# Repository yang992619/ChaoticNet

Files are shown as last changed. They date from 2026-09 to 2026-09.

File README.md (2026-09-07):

# ChaoticNet

双摆混沌系统的物理约束神经网络预测 · 物理竞赛项目（截稿 2026-09-15）

研究问题：在本科实验室级精度（初值估计 ±0.5°、60fps 手机相机、手动释放且初值由视频反演）下，对比纯数据驱动 (Reservoir Computing) 和物理约束 NN (PINN) 对混沌轨迹的可信预测窗口。论点：高保真物理建模 + 物理结构能把可信视界扩到 ESN 的数倍（Hybrid 仿真内约 7×、真实零样本约 2.7×）。

> 权威数字以 `data/canonical_results_B.md` 为准（分布质量 B 口径，`tools/demo_doctor.py` 自动核验）。文档/PPT/论文凡与之冲突的旧值均以此源为唯一真相。

---

## 一、目录结构

```
ChaoticNet/
├── README.md                       本文件，项目总入口
├── CHANGELOG.md                    变更日志（最新 v3.1）
│
├── 文档/                           所有中文文档（2026-06-23 起统一归档于此）
│   ├── 报告与计划/                  项目执行计划（14 周 + 5 人分工）、成员贡献说明、
│   │                               人工智能使用声明、实验仪器说明、审校报告、冲刺计划书
│   ├── 操作手册/                    拍摄操作说明书、相机标定教程、视觉追踪交接、实验清单
│   └── 答辩/                       答辩讲稿、逐页讲稿、PPT 大纲、学习清单
│
├── diagrams/                       图纸（理论 + 装置 + 加工）
│   ├── README.md                   3 张主图速览 + 关键设计理由
│   ├── 01_physics_model.svg        双摆理论模型（θ₁/θ₂/L₁/L₂/m₁/m₂）
│   ├── 02_mechanical_front_view.svg 装置正视装配图（含尺寸）
│   ├── 03_camera_setup_top_view.svg 视觉测量俯视布置
│   ├── 04_frame_assembly.svg       框架装配步骤
│   └── parts/                      四件加工图（发加工厂）
│       ├── BOM.md                  物料清单（576-753 元）
│       ├── 组装书.md                两天装配手册（含力矩 + 验收）
│       ├── 轴承.md                  MR105ZZ 轴承规格 + 脱脂步骤
│       ├── 轴销.md                  P05/P06 圆柱销规格（v2 已缩短至 12/15mm）
│       ├── generate_dxf.py         三件铝板 DXF 生成脚本
│       ├── P01_arm_1.{svg,pdf}     摆臂 1（6061-T6 4mm，R12.5）
│       ├── P02_arm_2.{svg,pdf}     摆臂 2（6061-T6 4mm，R12.5）
│       ├── P03_brass_weight.{svg,pdf}  配重盘 v2.1（45# 钢 ⌀30×12mm，66g）
│       ├── P04_pivot_bracket.{svg,pdf} 主轴座（6061-T6 5mm，R10）
│       └── dxf/                    四份 DXF 直接发激光厂
│
├── sim/                            数值仿真（GT 对照）
│   ├── baseline.py                 无阻尼 RK45 解拉格朗日方程，50 组随机初值
│   ├── baseline_distmass.py        分布质量 B 版（头条数据底座），50 组
│   ├── baseline_damped.py          阻尼版，实测拟合 b ≈ 1.66e-5 N·m·s/rad
│   ├── fit_damping.py              能量耗散率法从实测反推粘性 + 二次空气阻力
│   ├── lyapunov.py                 50 组自测最大 Lyapunov 指数 → τ_L
│   ├── visualize.py                4 张图（时间序列/xy 轨迹/相空间/能量）
│   ├── animate.py                  单次仿真摆动 mp4
│   ├── animate_compare.py          三色对比 mp4（GT 白 / ESN 蓝 / PINN 红）
│   ├── plot_horizon_50.py          50 组视界分布四联图
│   └── plot_three_way.py           ESN / PINN / Hybrid 三方对比图
│
├── rc/                             AI 预测模型
│   ├── esn.py                      Echo State Network 基线 (~290 行)
│   ├── pinn.py                     物理约束 NN 基线 (~350 行，含 model.pt 保存)
│   ├── hybrid.py                   解析-NN 混合模型 (~180 行)
│   ├── lnn.py                      Lagrangian NN（Cranmer 2020，训练不稳，归档 future work）
│   ├── sweep_50.py                 50 组 ESN+PINN 评估（无阻尼）
│   ├── sweep_damped.py             50 组 PINN vs Hybrid 评估（阻尼）
│   ├── real_validation_multi.py    29 段真实录像零样本评估
│   ├── error_decomposition.py      真实短视界的三天花板误差分解
│   └── sensitivity.py              ±0.1°/0.5°/1.0° 初值精度敏感性扫描
│
├── tools/                          自动化工具 + loop 监控
│   ├── smoke.py                    项目自检（< 30 秒）
│   ├── acceptance.py               W3 装置验收（τ / 重复性 / 棋盘格）
│   ├── paper_audit.py              paper/README/csv 一致性 loop（A–F 六项检查）
│   ├── demo_doctor.py              头条数字与 canonical_results_B.md 自动核验
│   ├── live_demo.py                答辩交互演示：评委输初值，看三摆赛跑
│   ├── overlay_real_prediction.py  实拍视频上叠加零样本预测轨迹
│   ├── build_canonical_distmass.py 训练并冻结 canonical 权重（分布质量）
│   ├── canon_multirun_distmass.py  多 run 头条统计（仿真内 + 真实）
│   ├── lambda_ablation_distmass.py 物理损失权重消融（分布质量重跑）
│   ├── hp_sweep.py                 PINN 超参/架构 sweep（写 leaderboard）
│   ├── fair_compare.py             公平四方对比（ESN/PINN/Hybrid/λ=0 同 N 同 epoch）
│   ├── multi_seed.py               多 seed 鲁棒性（3 λ × 5 seed）
│   └── data_size_ablation.py       训练数据量 ablation（2/5/10/20/50 trial）
│
├── tracking/                       视觉追踪
│   ├── track_pendulum.py           ★ 正式管线：29 段 canonical CSV 由它产出（HSV / Lab 双检测路径）
│   ├── reproduce_29.sh             由源视频重建 29 段逐帧 CSV（逐段 --t0/--t1，抽验 5 段 md5 一致）
│   └── track.py                    早期版本，仅合成视频验证（0.12° 中位误差），非论文数据来源
│
├── paper/                          论文（36 页 PDF，含 3 节消融附录）
│   ├── main.tex                    中文 LaTeX (ctex) 主文件，9 章 + 摘要 + 目录 + 文献 + 4 附录
│   ├── references.bib              24 篇文献（双摆/ESN/PINN/SciML/视觉/阻尼/气象大模型）
│   ├── texstyles/gb7714/           GB/T 7714—2015 参考文献样式（随项目自带）
│   ├── main.pdf                    编译产物（最新版本，36 页）
│   └── 编译说明.md                  xelatex + biber 编译流程（含 TEXINPUTS 设置）
│
└── data/                           所有数据 + 图
    ├── canonical_results_B.md              ★ 全项目数字唯一真相源（分布质量 B 口径）
    ├── sim_distmass/                       分布质量 B 仿真数据（头条数据底座）
    ├── canon_multirun/                     canonical 多 run 统计（论文头条表来源）
    ├── real_validation/                    29 段真实录像零样本结果 + 图
    ├── ablation_distmass/                  分布质量口径下的消融重跑
    ├── sim/                                无阻尼 baseline 数据
    │   ├── trial_000.csv ~ trial_049.csv   50 组仿真轨迹（30s @ 120fps）
    │   ├── summary.csv                     初值 + 能量漂移汇总
    │   └── figures/                        + v1_baseline 存档 + 三色对比 mp4
    ├── sim_damped/                         阻尼仿真数据（v3 ground truth）
    │   └── trial_000.csv ~ trial_049.csv   50 组阻尼轨迹
    ├── rc/                                 ESN 输出
    │   ├── esn_summary.csv / esn_summary_50.csv
    │   └── figures/
    ├── pinn/                               PINN 输出 + 权重缓存
    │   ├── pinn_summary.csv / pinn_summary_50.csv
    │   ├── train_history.csv / model.pt
    │   └── figures/
    ├── hybrid/                             Hybrid 输出
    │   ├── hybrid_summary_50.csv / model.pt
    │   └── train_history.csv
    ├── hybrid_damped/                      PINN vs Hybrid on 阻尼数据
    │   ├── pinn_summary_damped.csv / hybrid_summary_damped.csv
    │   ├── pinn_damped_model.pt / hybrid_damped_model.pt
    │   └── compare_damped.csv
    ├── sensitivity/                        初值精度敏感性
    │   ├── sensitivity.csv / sensitivity_summary.csv
    │   └── sensitivity_box.png
    ├── tracking/                           视觉追踪逐帧结果（459M，未入库，见 .gitignore）
    │   ├── tracked_<tag>.csv               29 段正式 CSV（74.6M）+ 新片 CSV + overlay 抽帧 PNG
    │   └── tracking_compare.png
    ├── tracking_windows/                   ★ 随仓库发布：29 段分析窗（每段前 600 帧，共 3.1M）
    ├── figures/                            汇总论文图
    │   ├── horizon_compare_50.png          50 组视界 4 联图
    │   ├── three_way_compare.png           三方对比图
    │   └── three_way_summary.csv
    ├── fair_compare/                       公平四方对比（N=32 共同混沌）
    ├── multi_seed/                         多 seed 鲁棒性 results + summary
    ├── data_size/                          数据量 ablation results + curve
    ├── hp_sweep/                           超参 sweep leaderboard
    ├── lnn/                                LNN 训练历史 + 50 组评估（归档）
    ├── acceptance/                         装置验收报告（已完成：标定 0.43px、τ≈130s、阻尼系数并入论文）
    ├── lyapunov.csv                        50 组自测 Lyapunov 指数
    ├── horizon_compare_50.csv              联合表
    └── v2_50trial_2026-06-11/              v2 完整快照（README + 所有图 + 权重）
```

---

## 二、当前进度（截至 2026-09-04）

### ✅ 已完成

| 类别 | 产出 | 状态 |
|---|---|---|
| 硬件设计 | 4 件加工图 SVG + DXF + PDF + BOM + 装配手册 | 可发厂 |
| 物理仿真 | sim/baseline.py 无阻尼版 + sim/baseline_damped.py 阻尼版 v3，各 50 组 | 可用 |
| 仿真可视化 | sim/visualize.py 4 张图 + sim/animate.py 单摆 mp4 | 已存档 |
| ESN 基线 | rc/esn.py，800 储池 | 已存档 |
| PINN 基线 | rc/pinn.py，128×4 MLP + 拉格朗日 loss + 权重缓存 model.pt | 已存档 |
| Hybrid 模型 | rc/hybrid.py，prior(解析 RHS) + 小残差 NN | 已实现 |
| 50 组 sweep | rc/sweep_50.py（无阻尼）+ rc/sweep_damped.py（阻尼） | 已跑 |
| 三方对比 | sim/plot_three_way.py，ESN/PINN/Hybrid 横向 | data/figures/ |
| 三色对比动画 | sim/animate_compare.py，GT 白 / ESN 蓝 / PINN 红 | 已生成 mp4 |
| 视觉追踪 | tracking/track.py，OpenCV HSV + 最小二乘圆拟合，0.12° 中位误差 | 合成视频已验证 |
| 初值敏感性 | rc/sensitivity.py，±0.1°/0.5°/1.0° × K=10 | 已扫描 |
| 消融实验 | λ多seed（3λ×5seed）+ data_size（5 档）+ hp_sweep | 已跑（分布质量重跑），进附录 |
| LNN | rc/lnn.py，Lagrangian NN（训练不稳，中位仅 0.08s） | 归档 future work |
| 一致性监控 | tools/paper_audit.py，paper/README/csv 六项（A–F）自动核对 | loop 可用，6/6 绿 |
| 论文 | paper/main.tex 36 页 PDF（竞赛格式：小四 + 24 磅行距 + 目录 + GB/T 7714 文献），24 篇文献，3 节消融附录，全 TODO 清零 | 已完成，持续精修 |
| 执行计划 | 文档/报告与计划/项目执行计划.md，14 周分阶段 + 5 人分工 | 可发群 |
| 交互演示 | tools/live_demo.py（评委输初值看三摆赛跑）+ tools/demo_doctor.py 一键自检 | 可现场演示 |
| 真实预测叠加 | tools/overlay_real_prediction.py，实拍视频上叠加零样本预测轨迹 | 已出演示视频 |
| 答辩 / 展示物料 | 答辩 PPT（嵌蝴蝶效应开场 + 29 段战绩墙，另有完整演示版）+ A3 深蓝高清海报 | 已出片 |

### 进度（截至 2026-09-04）

| 类别 | 任务 | 状态 |
|---|---|---|
| 硬件 | 加工件 + 淘宝件下单 → 到货 → 装配 | ✅ 已完成 |
| 实测 | 单摆 τ 衰减测试（目标 ≥ 30s） | ✅ 实测 τ≈130s，超标 4× |
| 视觉 | 棋盘格内参标定 + 实物视频跑 tracking | ✅ 标定 0.43px，29 段已追踪 |
| AI | 分布质量重训 PINN/Hybrid（sim→real 零样本，按设计不在真实数据上训练） | ✅ 已完成 |
| 论文 | 实测章节填充 + 消融分布质量重跑 + 竞赛格式改版 | ✅ 36 页，持续精修 |
| AI | Lagrangian NN（训练不稳，中位仅 0.08s） | 🟡 归档 future work |
| 协作 | git 本地版本控制 | ✅ 已建（尚未配置远程仓库，GitHub / Overleaf 待推）|
| 交付 | 匿名投稿版论文 + 作品介绍 + 海报 + 答辩 PPT | ✅ 已成套（截稿前持续精修）|

---

## 三、关键论点（分布质量模型，50 组仿真 + 29 段真实，多 run 诚实复算）

物理结构模型（PINN/Hybrid）显著优于纯数据 ESN，每个模型多次独立训练取 per-run 中位：

| 模型 | 视界 中位 | 归一化 / τ_L | 相对 ESN 提升 |
|---|---|---|---|
| ESN | 0.70s | 0.91 τ_L | 1× |
| PINN | 0.88s | 1.15 τ_L | 1.3× |
| 纯数据 MLP | 1.55s | 2.03 τ_L | 2.2× |
| Hybrid | 2.85s | 3.74 τ_L | 4.1× |

> **2026-09-08 ESN 闭环修正**：上表 ESN 行为修正后的值（旧值 0.40s / 0.53 τ_L，倍数 2.2/3.8/7.0）。
> 旧闭环预测入口把训练末帧输入喂了两遍，使预测窗第 0 帧即带约 1.9° 偏差。修正后 ESN 落在
> 文献报告的"约 1–2 个 Lyapunov 时间"区间内，说明基线未被削弱。根因、逐位等价验证与影响面清单见
> `tools/esn_closedloop_fix.py` 与 `data/esn_closedloop_fix/`。**真实零样本那张表不受影响**
> （真实侧调用本就与训练契约一致）。

仿真内混沌子集（每 run 取 horizon<9.9s）；ESN 多 reservoir seed 中位。真实零样本迁移（29 段）：
ESN 0.167s / 纯数据 0.358s / PINN 0.417s（2.5×）/ Hybrid 0.450s（2.7×）；物理损失真实增益 1.16×。

τ_L = 0.76s（分布质量 50 组扰动轨迹自测最大 Lyapunov 时间中位，sim/lyapunov.py）。
关键结论：sim→real 迁移首要驱动是仿真保真度（分布质量匹配真硬件，点质量 PINN 真实仅 0.27s）；
物理损失是分布迁移下的稳健性正则（仿真内反而无益），独立于 τ_L 绝对值估算。
完整数字来源 data/canonical_results_B.md。

初值敏感性（仿真内混沌子集 49 组，每档 K=20 次独立扰动，修正协议 tools/sensitivity_correct.py）：

| 扰动档 | PINN | Hybrid | 解析真解 |
|---|---|---|---|
| 无扰动 | 1.48s | 3.69s | 10.00s |
| σθ=0.45°（本研究实测） | 1.38s | 3.33s | 4.69s |
| σθ=1.0° | 1.15s | 2.35s | 2.47s |
| 联合（0.45° + 0.09 rad/s） | 1.33s | 2.82s | 3.45s |

读法：解析真解是唯一"纯净"的敏感性曲线（无扰动时逐位复现真值），它从 10s 塌到 3.45s，说明混沌放大真实存在；
而 PINN 只从 1.48 掉到 1.33（−10%），是因为模型自身的逼近误差已经大于这个量级的初值噪声。
所以结论不是"对初值稳健"，而是"当前瓶颈在模型逼近误差，不在初值精度"。
（注：早先版本的扫描协议把扰动逐位抵消了，模型看到的初值误差恒为 0，因此曾错误得出"越扰动视界越长、对初值稳健"。
诊断见 data/sensitivity_correct/old_protocol_diagnosis.txt。）
视觉追踪精度（合成视频，0.12° 中位误差）说明算法本身很准；真实拍摄下的初值状态估计噪声约 0.45°（来自实拍光照/反光/运动模糊），是真实视界的主要可改进来源之一。

### v2.1 消融发现（分布质量 B 口径重跑，2026-06；点质量期归档存于 data/*_pointmass_bak_20260621/）

训练数据量 ablation（PINN λ=1.0，全集 50 trial 评估，3 seed 均值）：

| 训练 trial 数 | 视界均值（3 seed） |
|---|---|
| 2 | 0.31s |
| 5 | 0.70s |
| 10 | 2.00s |
| 20 | 2.60s |
| 50 | 5.52s（注：训练=评估集，含 in-sample 重叠）|

反直觉发现：干净仿真数据上 phys loss 反而拖后腿（分布质量下更显著）。多 seed 验证（5 seed × 3 λ）：

| λ_phys | 视界均值（5 seed） |
|---|---|
| 0.0（纯数据 MLP）| 1.74s |
| 1.0（PINN）| 0.60s |
| 2.0 | 0.64s |

λ=0 在 5/5 个 seed 上都 > λ=1，稳健不是单 seed 巧合。解释：baseline 数据本身完美符合 Lagrangian，data loss 梯度已足够，phys loss 成冗余约束。已被 29 段真实数据证实：物理损失的价值在 sim→real 迁移才显现（真实 λ=0.1 中位 0.42s > λ=0 的 0.36s）。

---

## 四、关键决策已锁定（不要再讨论）

| 决策 | 已锁定值 | 理由 |
|---|---|---|
| 摆长 | L₁=250mm, L₂=200mm | 非对称避退化模态，手机视场可框入 |
| 摆臂 | 6061-T6 铝板 4mm 厚 | 匹配 MR105ZZ 4mm 宽 |
| 轴承 | MR105ZZ ×2（脱脂 + 钟表油） | 目标 τ ≥ 30s（实测 τ≈130s，超标 4×）|
| 配重 | P03 v2.1 45# 碳钢 ⌀30×12mm，66g | 钢比黄铜便宜、刚度足够 |
| 初值精度 | 手动释放，初值从视频反演（估计不确定度 ≈0.5°） | 本科实验室级，本身是论文论证对象 |
| 相机 | 真实 60fps（手机即可）；仿真采样 120fps | 实测最大角频率 4.11 Hz（29 段 41 万帧峰值），60fps 约 15× 过采样，视界按秒算与帧率无关 |
| 视觉标记 | 方形彩色贴片（铰接处蓝、末端浅红，等效直径约 12/16mm）| 实拍实际采用；BOM 里的 3M 反光荧光红 ⌀5mm 圆点属设计方案，29 段未用 |
| 背景 | 摆后方深色织物（画面两侧可见浅色墙面）| 实拍实际采用；BOM 里的哑光黑亚克力背板属设计方案，29 段未用 |

详细论证见 `diagrams/README.md` 节"关键设计理由"。

---

## 五、快速上手

### 环境

```bash
pip3 install --break-system-packages --user -r requirements.txt
```

LaTeX（论文编译）：brew install --cask basictex 然后 `sudo /Library/TeX/texbin/tlmgr install ctex biblatex biber physics cleveref subcaption algorithms enumitem titlesec booktabs setspace`
GB/T 7714—2015 文献样式已随项目放在 `paper/texstyles/gb7714/`，编译时带上 `TEXINPUTS="./texstyles/gb7714//:"` 即可，无需另装。

### 一键复现（从零到 36 页 PDF）

```bash
python3 tools/smoke.py                      # 项目自检 < 30 秒

# 1. 分布质量仿真数据 + Lyapunov（tau_L）
python3 sim/baseline_distmass.py            # 分布质量 50 组轨迹（头条数据底座），~1 分钟
python3 sim/baseline_damped.py              # 阻尼场景（第八节限制，可选 --b 7e-4）
python3 sim/lyapunov.py                     # 实测最大 Lyapunov 指数 -> tau_L≈0.76s

# 2. canonical 头条（仿真内 + 真实零样本，多 run 中位[IQR]）
python3 tools/build_canonical_distmass.py   # 训练并冻结 canonical 权重 data/pinn|hybrid/model.pt
python3 tools/canon_multirun_distmass.py    # 多 run 统计 -> tab:horizon-compare + tab:real-horizon（25 次训练，最耗时的一步）
python3 rc/real_validation_multi.py         # 29 段真实零样本 -> summary_multi.csv（需 data/tracking/*）

# 3. 消融
python3 tools/lambda_ablation_distmass.py   # 物理损失权重 {0,1,2}×5seed -> tab:ablation-lambda
python3 tools/data_size_ablation.py         # 训练数据量 -> tab:ablation-data

# 4. 论文图 + 编 PDF
python3 sim/plot_three_way.py               # 三方对比图
python3 rc/error_decomposition.py           # 三天花板误差分解图
cd paper && TEXINPUTS="./texstyles/gb7714//:" latexmk -xelatex main.tex   # 36 页 PDF
```

全流程 CPU 约 1 小时量级（以多 run 训练为主，机器更慢则更长）。注意 build_canonical_distmass.py 每次都会重新训练，不做权重缓存判断。
旧 λ=1.0 基线脚本 `rc/sweep_50.py` / `sweep_damped.py` / `sensitivity.py` 仍可单独跑做对照，
但**非论文头条来源**；`sweep_50` 权重独立缓存在 `data/pinn/sweep50_model.pt`，不会覆盖 canonical。
真实零样本需 `data/tracking/*.csv`（245M，未入库）；无追踪数据时直接读已入库的
`data/real_validation/summary_multi.csv` 复核头条。

自检 + 一致性监控：

```bash
python3 tools/smoke.py               # 项目自检 < 30 秒
python3 tools/paper_audit.py         # paper/README/csv 六项一致性核对（A–F）
```

### 看 PDF 加工图

```bash
open diagrams/parts/P01_arm_1.pdf    # 任意 P01-P04
```

### 发给加工厂

把 `diagrams/parts/dxf/` 里 4 个 DXF + 对应 PDF 打包发激光切割厂 / 机加工厂。话术见 `diagrams/parts/BOM.md` 节"给加工厂打招呼"。

---

## 六、下一步阅读

1. `文档/报告与计划/项目执行计划.md` —— 14 周完整计划、5 人分工、风险预案、阶段验收
2. `diagrams/parts/BOM.md` —— 采购清单 + 验收
3. `diagrams/parts/组装书.md` —— 两天装配 SOP
4. `diagrams/README.md` —— 关键设计决策背后的物理理由

---

## 七、版本

| 版本 | 日期 | 改动 |
|---|---|---|
| v1.0 | 2026-06-11 | 初版。装置设计冻结，仿真 + ESN + PINN 三个基线落地 |
| v2.0 | 2026-06-11 | 加 Hybrid 模型 + 50 组完整 sweep + 阻尼仿真 + tracking + 初值敏感性 + 9 页论文 PDF |
| v2.1 | 2026-06-12 | loop 模式上线（paper_audit/hp_sweep/fair_compare）+ 多 seed/数据量消融 + LNN 归档 + 14 页论文 PDF |
| v3.0 | 2026-06-21 | 分布质量 B 迁移（点质量→分布质量，主口径切换）+ 真实零样本全管线（29 段实拍，Hybrid 2.7×）+ 工程质量五项闭环 + git 版本控制上线 + 19 页论文 PDF |
| v3.1 | 2026-09-04 | 答辩交付物成套（交互演示 live_demo + 实拍预测叠加 + PPT/海报）+ 文档归入 文档/ + 口径清扫 + 论文竞赛格式改版 19→32 页（目录 / 小四 24 磅 / GB/T 7714 文献，24 篇）|

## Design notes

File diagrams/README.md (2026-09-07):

# ChaoticNet 装置图纸

三张 SVG 图纸，覆盖论文从理论模型到实验装置到测量布置的完整说明链。

## 三张图速览

| 文件 | 用途 | 对应论文章节 |
|---|---|---|
| `01_physics_model.svg` | 双摆理论模型示意：θ₁/θ₂、L₁/L₂、m₁/m₂、g、坐标系、拉格朗日量 | 第 2 章 双摆系统动力学理论 |
| `02_mechanical_front_view.svg` | 实物装置正视装配图：2020 框架、摆臂、轴承、配重、视觉标记，含完整尺寸 | 第 3 章 实验装置（含附录 E 加工图纸基础） |
| `03_camera_setup_top_view.svg` | 视觉测量俯视布置：相机、双 LED、棋盘格、距离参数、视场 | 第 3 章 视觉测量系统 |

## 用什么软件改

- **直接看 / 投到论文里**：任何浏览器 / Preview / VSCode 都行；插入 LaTeX 用 `\includegraphics` 即可（`pdflatex` 不直接吃 SVG，先 `rsvg-convert -f pdf in.svg -o out.pdf` 或 `cairosvg` 转 PDF）。
- **想可视化拖拽编辑**：Sketch、Figma 都能开 SVG；专业的用 **Inkscape**（免费、Mac 上 `brew install inkscape`）。
- **代码改**：纯文本 SVG，用 VSCode/Sublime 编辑 XML 标签即可。

## 关键设计理由（评委可能问）

### 为什么 L₁=250、L₂=200（非对称）

- 双摆对称（L₁=L₂）时存在退化对称模态，混沌窗口更窄；非对称比例（L₁ > L₂ × 1.25）能在更宽初值范围内进入完整混沌。
- 选 250/200 是手机相机视场 1m 距离下能完整框入的尺寸，再大相机要拉远。

### 为什么用 MR105ZZ 而不是更便宜的塑料套筒

- 衰减时间常数（自由摆动后摆幅减半所需时间）是关键工程指标。塑料/铜套筒摩擦大，τ < 10s，意味着真正混沌阶段不到 5 秒就被摩擦吃掉。
- MR105ZZ + 钟表油，目标 τ ≥ 30s（实测待单摆衰减测试补），留出足够的"干净"混沌窗口给 AI 训练数据。
- 选 5mm 内孔是为了配合 M3 螺栓和摆臂厚度公差。

### 为什么是 ±0.5° 而不是更高精度

- 半导体激光 + CCD 行扫描能做到 ±0.05°，但需要 1.5 万元的传感器。
- 初值状态由视频反演、估计不确定度约 ±0.5°，工程级足够——这本身就是论文要论证的：**"在普通本科实验室条件下 AI 预测的可用边界"**。（注：装置用手动释放，不依赖精确释放机构；模型吃的初值是从视频量出来的。）
- 5.4 章会做初值精度敏感性扫描（1e-1 到 1e-5 扰动），用真实精度去映射预测可靠窗口，这才是有研究价值的事情。

### 为什么相机 60fps 就够

- 双摆固有频率 ω₀ ≈ √(g/L) ≈ 6.3 rad/s ≈ 1 Hz，混沌阶段瞬时角速度峰值 ~20 rad/s。
- 60 fps 的 Nyquist 上限是 30 Hz，对 20 rad/s ≈ 3.2 Hz 的运动有 ~19× 过采样，足够无混叠重建。
- 更高帧率多出来的精度被相机抖动和荧光点定位精度抵消，没有实际收益但数据量翻倍。
- 真实数据集 29 段统一用 1080p@60fps；几乎所有近 3 年的手机都支持，多数也支持 120fps 慢动作（仅早期测试用过，未纳入数据集）。仿真内部采样用 120fps，是数值选择、与相机无关。

### 为什么背板是哑光黑亚克力

- 视觉追踪管线第一步是颜色阈值分割，反光红荧光点在哑光黑背板上的 RGB 分离度最大。
- 哑光（不是亮面黑）防止 LED 直射反光形成假"红点"。
- 亚克力比黑纸耐用，不会因为摆动气流变形。

## 后续要补的图（如果时间允许）

- 摆臂 1 详细加工图（DXF 用），论文附录 E
- 摆臂 2 加工图含配重孔位
- 系统总体流程图（数据流：视频 → 追踪 → CSV → RC/LSTM → 预测）

## 注意

所有尺寸以 SVG 内文字标注为准，不要用浏览器放大率反推实际尺寸。下料前用 Inkscape 打开打 1:1 印刷可作为加工模板。

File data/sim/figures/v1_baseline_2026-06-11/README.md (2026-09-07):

# v1 基线图 · 2026-06-11

这四张图是 ChaoticNet 项目仿真阶段的第一组基线产物，存档保留，避免后续重跑 visualize.py 被覆盖。

## 文件清单

| 图 | 内容 | 用途 |
|---|---|---|
| fig_single_trial_000.png | 单次仿真四联图（θ-t / xy 轨迹 / 相空间 / 能量漂移） | 给队友/导师看"仿真长啥样" |
| fig_butterfly.png | 蝴蝶效应：两条差 0.1° 的轨迹对比 + log 偏差 | 答辩/论文的混沌敏感性招牌图 |
| fig_energy_sweep.png | 50 组能量漂移直方图 + 初值散点 | 论文方法章节，证明求解器精度 |
| fig_phase_grid.png | 12 组不同初值的相空间形态对比 | 看混沌轨迹多样性 |

## 参数（来自 sim/baseline.py v1.0）

- L₁=250mm, L₂=200mm
- m₁=25g, m₂=66g (P03 v2.1 45# 钢盘)
- g=9.81 m/s²
- RK45, rtol=1e-10, atol=1e-12
- 30s @ 120fps

## 后续

如果改参数（比如加摩擦项、换配重质量），新图存到 `v2_*` 文件夹，本目录保留作为对照。

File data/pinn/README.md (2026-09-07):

# data/pinn/ — PINN 权重与训练产物

## 唯一正式权重：model.pt

**`model.pt`（2026-06-19，MD5 `9331eb365f67e5e3646bf9aede67059b`）是本项目 PINN 的唯一正式权重，
对应 B 版「分布质量」（distributed mass）物理参数。论文正文、答辩材料、
data/canonical_results_B.md 中所有 PINN 相关数字，全部来自这份权重。**

加载它的脚本（勿改路径）：

- `rc/real_validation.py` / `rc/real_validation_multi.py` —— 真实数据零样本验证
- `rc/lam0_real_baseline.py` —— λ=1（物理约束）对照分支
- `sim/animate_compare.py` —— 三方对比动画（缓存权重；文件缺失时会即时重训 3–5 分钟）
- `tools/smoke.py` —— 自检时检查该文件存在

## 已移走的旧权重（2026-09-04）

以下两份历史权重原本与 `model.pt` 混放在本目录，现已移至
`archived/old_models/`：

| 文件 | 日期 | 内容 | MD5 |
|---|---|---|---|
| `model_pointmass.pt` | 2026-06-17 | 点质量（point mass）旧版模型，对应已废弃的 3.4× 那套数字 | `40fd16c6144284f729fc9f9d81a7145f` |
| `model_oldparams.pt` | 2026-06-11 | 更早的一版旧参数模型 | `d6e2c01c3a1b4979fd82da36157080b0` |

**移走原因**：三份权重同名前缀、同目录、体积相近（均约 200 KB），
任何脚本若误写成 `torch.load('data/pinn/model_pointmass.pt')`，PyTorch 会**静默加载**
旧模型——不报错、不告警，直接产出错误数字，且从结果上很难察觉。
2026-07-13《项目体检报告》将此列为🟠高优先级风险项。移动前已全仓 grep 确认
**没有任何代码引用这两个文件名**（仅体检报告和计划书等文档提及），因此移动不影响任何脚本。

**这两份旧权重的输出数字一律不得引用。** 它们仅作历史追溯保留。

## 其他文件

- `pinn_summary.csv`（06-11）、`pinn_summary_50.csv`（06-17）—— 训练/评测汇总表
- `train_history.csv` —— 训练损失历史
- `figures/` —— 训练曲线与预测对比图；`figures/v1_baseline_2026-06-11/` 是 v1 旧基线图，另见其内 README

## 规矩

往本目录新增权重前，先想清楚：如果它不该被当成正式权重用，就别放这儿——
放 `archived/old_models/` 并在上表补一行。本目录**只应存在一份 `.pt`**。

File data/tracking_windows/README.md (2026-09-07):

# 分析窗数据集（tracking_windows）

29 段真实双摆录像的追踪结果，每段截取起始 600 帧（10 s @ 60 fps），合计约 3.0 MB。

本目录由 `tools/make_tracking_windows.py` 从 `data/tracking/` 下的逐帧全量结果截取生成
（29 段 CSV 共约 71 MB；连同 QC 叠加图，整个 `data/tracking/` 约 440 MB，均不随仓库分发），
列定义与全量结果完全一致：

`frame, t, x_m1_px, y_m1_px, x_m2_px, y_m2_px, area_m1, area_m2, th1, th2, w1, w2`

其中 `th1/th2` 为反演角度（rad），`w1/w2` 为角速度（rad/s），像素坐标为 1920×1080 口径。

分析窗完整覆盖论文所用的 4 s 引入窗与 4 s 预测窗，因此仅凭本目录即可复现
论文的真实零样本结果。逐帧全量结果与源视频（约 13 GB）不随仓库分发，
但可由 `tracking/reproduce_29.sh` 从源视频完整重建。

`MD5SUMS` 为各段校验和，可用 `md5sum -c MD5SUMS`（macOS：`md5 -r`）核对。

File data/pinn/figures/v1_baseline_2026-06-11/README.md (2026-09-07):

# v1 PINN 基线图 · 2026-06-11

Physics-Informed Neural Network 闭环预测结果，存档保留作 v2/v3 的对照。

## 超参（rc/pinn.py v1.0）

| 参数 | 值 |
|---|---|
| 网络 | MLP, 6 → 128 ×4 层 → 2 |
| 输入编码 | (sinθ, cosθ, ω/10) ×2 = 6 维 |
| 输出归一化 | ω̇ / 100 |
| 数据 loss | MSE(ω̇_pred / 100, ω̇_truth / 100) |
| 物理 loss | (M(θ)·ω̇ - b(θ,ω))² 均值，在 2048 个随机 collocation 点 |
| 损失权重 | λ_phys = 1.0 |
| 优化器 | Adam，lr 2e-3 → cosine 衰减 |
| epoch | 300 |
| batch | 512 |
| 训练集 | trial 0-4 的前 20s × 120 fps |
| 闭环预测 | RK4，dt = 1/120 s |
| 视界阈值 | 角度欧氏偏差 > 10° |

## 结果对比 vs ESN baseline

| trial | ESN 视界 | PINN 视界 | 提升 |
|---|---|---|---|
| 000 | 0.12s | 1.49s | 12× |
| 001 | 0.11s | 2.37s | 21× |
| 002 | 0.16s | 0.23s | 1.4× (难) |
| 003 | 10.00s | 10.00s | — (准周期) |
| 004 | 0.12s | 3.14s | 26× |

不含准周期的平均提升约 15 倍。

## 论文核心论点（已成立）

物理约束 NN 把混沌可信预测窗口从 1 个 Lyapunov 时间拉到约 15 个。

## v2 改进方向

- 加 Lagrangian Neural Network（学 L(θ,ω) 直接，自动满足欧拉-拉格朗日）
- Hybrid：RC fast pass + PINN residual correction
- 引入摩擦项（实测数据有阻尼）
- 在 50 组完整 sweep 上跑 + Lyapunov 时间归一化
- 初值精度敏感性扫描（论文 5.4 章）

存档保留作 v2/v3 的对照基线。

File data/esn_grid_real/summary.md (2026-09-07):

# 真实侧 ESN「引入窗长度 × 超参」二维扫描

> 一句话结论候选：**纯数据 ESN 需要每段多少秒实测数据现场自训，才能追平**
> **一秒真实数据都不用的零样本物理模型？** 下面把这条交叉曲线测出来。

脚本 `tools/esn_grid_real.py`（新建，不改 rc/esn.py 与 rc/real_validation_multi.py）。
产物目录 `data/esn_grid_real/`。单进程，BLAS 线程全设 1。用时 367.6 min。

## 0. 自证门槛（全部通过才有下文）

- G1 融合路径 vs rvm.run_esn 逐位等价：θ1 maxdiff=0.000e+00 θ2 maxdiff=0.000e+00  [PASS]
- G2 canonical-real+lead4+seed42 逐片复现 summary_multi.csv 的 ESN_h：29 片最大差=4.510e-04 (<1e-3)，中位=0.1501s  [PASS]
- G3 lead=   4s 对照组：PINN=0.4168(期望0.417) Hybrid=0.4835(期望0.484)  [PASS]
- G3 lead=  16s 对照组：PINN=0.8837(期望0.884) Hybrid=1.0004(期望1.0)  [PASS]
- G3 lead=  32s 对照组：PINN=1.2839(期望1.284) Hybrid=1.2672(期望1.267)  [PASS]

## 1. 论文缺失的真实侧 ESN 配置（必须补进附录）

| 名称 | n_res | ρ | leak | ridge | washout | 出处 |
|---|---|---|---|---|---|---|
| canonical-real（**真实侧实跑值**） | 300 | 0.95 | 0.3 | 1e-3 | 50 | `rc/real_validation_multi.py:95` |
| paper-ESN（**论文附录超参表**） | 800 | 0.95 | 0.25 | 1e-5 | 200(仿真侧) | 论文附录 / `rc/esn.py:189-191` |

两者**不是同一套**。论文真实侧报的 0.167s 来自上面那一行，读者按附录那一行根本复现不出来。
washout 在真实侧还会被 `min(washout, lead_n//3)` 截断（lead=4 时 lead_n=239 → 79），
所以 paper-ESN 在 washout=50 与 200 两种写法下也不同，本报告两种都跑（见 leaderboard）。

## 2. 主表：各 lead 档的中位视界（29 片，4s 预测窗，seed=42）

**删失说明（硬性）**：预测窗固定 4.0s（实际 239 帧 ≈ 3.985s）。整窗未超 10° 阈值的片记为
**右删失**，其视界值等于窗长，是真值的**下界**。因此表中的中位在有删失时是**下界**；
删失率 ≥50% 时中位不可估计，只能写 `>3.985`。

| lead (s) | ESN canonical-real | 删失 | ESN paper-cfg | 删失 | ESN 网格最优 | 删失 | 最优配置 | PINN | Hybrid | MLP(λ=0) |
|---|---|---|---|---|---|---|---|---|---|---|
| 2 | ≥0.100 | 1/29 (3%) | ≥0.133 | 1/29 (3%) | 0.150 | 0/29 (0%) | 400/1.1/0.1/1e-06 | 0.333 | 0.600 | 0.333 |
| 4 | ≥0.150 | 1/29 (3%) | ≥0.167 | 2/29 (7%) | ≥0.183 | 3/29 (10%) | 400/0.7/0.1/1e-06 | 0.417 | 0.484 | 0.267 |
| 8 | ≥0.267 | 4/29 (14%) | ≥0.317 | 5/29 (17%) | ≥0.534 | 5/29 (17%) | 1600/0.95/0.5/0.0001 | 0.584 | 0.717 | 0.417 |
| 16 | ≥0.350 | 4/29 (14%) | ≥0.650 | 8/29 (28%) | ≥1.234 | 8/29 (28%) | 1600/0.95/0.25/0.0001 | 0.884 | 1.000 | 0.984 |
| 32 | ≥1.467 | 6/29 (21%) | ≥2.184 | 9/29 (31%) | ≥3.735 | 14/29 (48%) | 1600/0.95/0.1/0.0001 | 1.284 | 1.267 | ≥1.050(删1) |
| 64 | ≥2.151 | 9/29 (31%) | >3.985 | 21/29 (72%) | >3.985 | 21/29 (72%) | 1600/0.7/0.1/0.0001 | ≥2.184(删3) | ≥2.151(删3) | 1.351 |

## 3. 倍数表（分母 = ESN）与交叉点

倍数在 ESN 删失时是**上界**（因为 ESN 中位是下界）。所以「倍数 < 1，即 ESN 反超」
这个方向的结论是**安全的**；而交叉之后倍数具体是多少，只能报为下界（1/上界）。

| lead (s) | PINN/ESN(canon) | Hybrid/ESN(canon) | MLP/ESN(canon) | PINN/ESN(best) | Hybrid/ESN(best) | ESN 删失(canon/best) |
|---|---|---|---|---|---|---|
| 2 | ≤3.33× | ≤6.00× | ≤3.33× | 2.22× | 4.00× | 1/0 |
| 4 | ≤2.78× | ≤3.22× | ≤1.78× | ≤2.27× | ≤2.64× | 1/3 |
| 8 | ≤2.19× | ≤2.69× | ≤1.56× | ≤1.09× | ≤1.34× | 4/5 |
| 16 | ≤2.52× | ≤2.86× | ≤2.81× | ≤0.72× | ≤0.81× | 4/8 |
| 32 | ≤0.88× | ≤0.86× | ≤0.72× | ≤0.34× | ≤0.34× | 6/14 |
| 64 | ≤1.02× | ≤1.00× | ≤0.63× | ≤0.55× | ≤0.54× | 9/21 |

**交叉点（粗档，`LEADS_MAIN`）：**

- **Hybrid vs canonical-real ESN**：倍数在 lead ∈ (16s, 32s] 之间跌破 1.0 —— 即纯数据 ESN 需要每段 **16–32 秒**实测数据现场自训，才能追平一秒真实数据都不用的零样本物理模型。
- **PINN vs canonical-real ESN**：倍数在 lead ∈ (16s, 32s] 之间跌破 1.0 —— 即纯数据 ESN 需要每段 **16–32 秒**实测数据现场自训，才能追平一秒真实数据都不用的零样本物理模型。
- **Hybrid vs 网格最优 ESN**：倍数在 lead ∈ (8s, 16s] 之间跌破 1.0 —— 即纯数据 ESN 需要每段 **8–16 秒**实测数据现场自训，才能追平一秒真实数据都不用的零样本物理模型。
- **PINN vs 网格最优 ESN**：倍数在 lead ∈ (8s, 16s] 之间跌破 1.0 —— 即纯数据 ESN 需要每段 **8–16 秒**实测数据现场自训，才能追平一秒真实数据都不用的零样本物理模型。

## 4. canonical-real 在网格里排第几

| lead (s) | canonical-real 中位 | 网格内排名 | 网格最优中位 | 最优/canonical |
|---|---|---|---|---|
| 2 | 0.100 | #132/147 | 0.150 | 1.50× |
| 4 | 0.150 | #59/147 | 0.183 | 1.22× |
| 8 | 0.267 | #69/147 | 0.534 | 2.00× |
| 16 | 0.350 | #88/147 | 1.234 | 3.52× |
| 32 | 1.467 | #77/147 | 3.735 | 2.55× |
| 64 | 2.151 | #95/123 | 3.985 | 1.85× |

## 5. 按摆幅分层的交叉点

分层变量 = **引入窗末 2 秒内的 |θ1| 峰值**（`amp_leadend_deg`），它随 lead 增大而
因阻尼衰减，是「窗口后移让题目变简单」这个混淆的直接度量。同表给出同窗口物理模型，
所以分层比较仍然公平。

| lead (s) | 摆幅带 | n | ESN(canon) 中位 | ESN 删失 | PINN 中位 | Hybrid 中位 | Hybrid/ESN |
|---|---|---|---|---|---|---|---|
| 2 | 40–60° | 4 | 0.784 | 0/4 | 1.309 | 1.301 | 1.66× |
| 2 | >60° | 24 | 0.083 | 0/24 | 0.283 | 0.367 | 4.40× |
| 4 | 40–60° | 6 | 0.400 | 0/6 | 0.934 | 1.125 | 2.81× |
| 4 | >60° | 22 | 0.150 | 0/22 | 0.367 | 0.400 | 2.67× |
| 8 | 40–60° | 9 | 0.667(下界) | 2/9 | 0.600 | 0.667 | ≤1.00× |
| 8 | >60° | 19 | 0.167(下界) | 1/19 | 0.550 | 0.717 | ≤4.30× |
| 16 | 40–60° | 13 | 0.634(下界) | 2/13 | 0.984 | 0.884 | ≤1.39× |
| 16 | >60° | 14 | 0.192(下界) | 1/14 | 0.834 | 0.917 | ≤4.78× |
| 32 | 20–40° | 4 | 3.985(下界) | 3/4 | 1.976 | 1.984 | ≤0.50× |
| 32 | 40–60° | 21 | 1.201(下界) | 3/21 | 1.150 | 1.084 | ≤0.90× |
| 32 | >60° | 4 | 1.509 | 0/4 | 1.084 | 1.059 | 0.70× |
| 64 | 20–40° | 21 | 2.151(下界) | 6/21 | 2.568 | 2.401 | ≤1.12× |
| 64 | 40–60° | 8 | 2.443(下界) | 3/8 | 1.892 | 1.834 | ≤0.75× |

## 7. 诚实警告（写进论文时必须一起写）

1. **删失是本表最大的软肋**。4s 预测窗对 lead≥16s 的 ESN 已经不够用，中位顶到窗上沿。
   交叉点（倍数跌破 1）的结论安全，但「ESN 反超 N 倍」这种说法只能报下界。
   要给出无删失的数字，必须把预测窗放长重跑（与第 5 项 window_mining_v2 同一思路）。
2. **lead 变大同时改了两件事**：ESN 见到的训练数据变多 **且** 预测窗后移导致摆幅因阻尼
   衰减、题目变简单。本报告用**同窗口 PINN/Hybrid/MLP 对照**分离这两件事——对照组
   一秒真实数据都不用，它们的视界随 lead 的增长量就是「题目变简单」的纯效应。
3. **ESN 与物理模型的信息量本就不对等**：ESN 在**待预测那一段轨迹自己的前 lead 秒**上
   在线自训；PINN/Hybrid 只见过仿真，对这段真实录像是**零样本**。因此这不是
   「谁更强」，而是「跳过物理先验要付多少数据代价」。
4. **低幅带的 ESN 长视界不等于混沌预测能力**：摆幅小的时候系统接近准周期，
   ESN 在做近周期外推，不是在预测混沌。措辞不要误导。

## 8. 运行备注

- Stage1 因墙钟预算被截断，leaderboard 可能不完整。

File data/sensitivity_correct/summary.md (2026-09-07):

# 初值敏感性扫描（修正协议） — data/sensitivity_correct/

生成时间：2026-09-05 16:20:41　脚本 `tools/sensitivity_correct.py`
参数：K=20 次/档，仿真 50 trial（t=20s→30s，10s 窗），真实 29 段（lead=4.0s/pred=4.0s），阈值 10.0°

## 0. 一句话结论

仿真内 PINN 中位视界由无扰动 1.48s 降到实测联合档（σθ=0.45°、δω=0.09 rad/s）1.33s。σθ 四档单调性实测：PINN**非单调**、MLP_lam0单调、Hybrid单调、Analytic单调。

论文 tab:sensitivity 现在写的「稳健、无系统性塌缩」，其根因是旧协议把扰动逐位抵消（模型看到的初值误差恒为 0，见 `old_protocol_diagnosis.txt`），而非物理上真的稳健。

> 读表注意（如实标注）：Analytic（解析真解）是唯一的**纯净**敏感性曲线——它无扰动时逐位复现真值（视界顶到窗长 10s），因此扰动是它唯一的误差源，塌缩必然单调。PINN/MLP/Hybrid 自身带模型逼近误差，小扰动有时会与模型偏差部分抵消，个别档位出现视界不降反升属正常，不要当成「稳健」的证据；看趋势与联合档即可。

## 1. 自证门槛

- G1 [硬] trial_000 / PINN / 无扰动视界 = 5.841666666666667（期望 701/120 = 5.841666666666667）→ PASS
- G2 [硬] Analytic RK4(sub=8) 无扰动 vs 存档轨迹最大角差 2.23e-05°，视界 10.0s → PASS
- G3 [硬] 真实侧 29 段 PINN/Hybrid 无扰动 vs summary_multi.csv 最大差 4.92e-04 → PASS
- G4 [软] trial_000 PINN σθ 四档单调下降 = True；逐档值 vs 探针见 self_check.txt

> 说明：探针给的逐档值（4.596/2.325/1.763）是单条 trial 上 K 次随机抽样的中位，换随机流本来就会抖 0.1–0.5s（K=20 时单 trial 的 min–max 跨度实测可达 1.0–6.5s），因此只有确定性的 G1/G2/G3 做硬门槛。

## 2. 可直接替换 tab:sensitivity 的新表（仿真内，混沌子集）

口径：50 组轨迹中「**PINN** 无扰动视界 < 9.9s」的混沌子集（子集在 σ=0 处一次定死，跨档、跨模型都不变，保证可比），每档 K=20 次独立高斯扰动，报所有 trial×rep 的中位 [IQR]。

### 角度扰动 σθ

| 扰动档 | PINN | MLP_lam0 | Hybrid | Analytic |
|---|---|---|---|---|
| clean | 1.48 [0.84, 2.62] | 1.28 [0.57, 1.91] | 3.69 [3.14, 6.20] | 10.00 [10.00, 10.00] |
| th0.1 | 1.43 [0.82, 2.62] | 1.28 [0.57, 1.91] | 3.68 [2.98, 5.91] | 10.00 [7.26, 10.00] |
| th0.45 | 1.38 [0.80, 2.50] | 1.18 [0.57, 1.92] | 3.33 [2.05, 6.20] | 4.69 [2.53, 10.00] |
| th0.5 | 1.39 [0.78, 2.51] | 1.18 [0.56, 1.92] | 3.27 [1.88, 6.12] | 4.24 [2.36, 10.00] |
| th1.0 | 1.15 [0.68, 2.39] | 1.07 [0.54, 1.83] | 2.35 [1.18, 4.39] | 2.47 [1.25, 8.41] |

### 角速度扰动 σω

| 扰动档 | PINN | MLP_lam0 | Hybrid | Analytic |
|---|---|---|---|---|
| clean | 1.48 [0.84, 2.62] | 1.28 [0.57, 1.91] | 3.69 [3.14, 6.20] | 10.00 [10.00, 10.00] |
| w0.03 | 1.40 [0.82, 2.63] | 1.27 [0.57, 1.93] | 3.66 [2.90, 5.80] | 10.00 [6.59, 10.00] |
| w0.09 | 1.35 [0.81, 2.53] | 1.19 [0.57, 1.93] | 3.35 [2.25, 5.73] | 6.55 [2.77, 10.00] |
| w0.2 | 1.18 [0.67, 2.13] | 1.10 [0.52, 1.80] | 2.60 [1.35, 4.44] | 3.12 [1.54, 9.27] |

### 实测联合档

| 扰动档 | PINN | MLP_lam0 | Hybrid | Analytic |
|---|---|---|---|---|
| clean | 1.48 [0.84, 2.62] | 1.28 [0.57, 1.91] | 3.69 [3.14, 6.20] | 10.00 [10.00, 10.00] |
| joint_0.45_0.09 | 1.33 [0.78, 2.37] | 1.15 [0.57, 1.92] | 2.82 [1.72, 5.05] | 3.45 [2.02, 10.00] |
| det_joint_0.45_0.09 | 1.39 [0.82, 2.66] | 1.28 [0.57, 1.92] | 3.21 [2.16, 4.42] | 6.17 [2.44, 10.00] |

### 全 50 trial（含非混沌 trial，仅供参考）

| 扰动档 | PINN | MLP_lam0 | Hybrid | Analytic |
|---|---|---|---|---|
| clean | 1.54 [0.85, 2.64] | 1.30 [0.57, 1.93] | 3.75 [3.15, 6.21] | 10.00 [10.00, 10.00] |
| th0.1 | 1.47 [0.82, 2.65] | 1.29 [0.57, 1.93] | 3.69 [3.04, 6.20] | 10.00 [7.35, 10.00] |
| th0.45 | 1.45 [0.81, 2.62] | 1.19 [0.57, 2.06] | 3.35 [2.07, 6.53] | 4.85 [2.56, 10.00] |
| th0.5 | 1.45 [0.79, 2.62] | 1.19 [0.57, 2.10] | 3.30 [1.91, 6.37] | 4.32 [2.38, 10.00] |
| th1.0 | 1.18 [0.68, 2.51] | 1.09 [0.55, 1.88] | 2.42 [1.19, 4.79] | 2.51 [1.26, 9.61] |
| w0.03 | 1.46 [0.83, 2.64] | 1.28 [0.57, 1.94] | 3.67 [2.98, 6.13] | 10.00 [6.61, 10.00] |
| w0.09 | 1.40 [0.82, 2.62] | 1.20 [0.57, 2.02] | 3.40 [2.28, 5.90] | 6.71 [2.90, 10.00] |
| w0.2 | 1.23 [0.69, 2.18] | 1.11 [0.53, 1.86] | 2.63 [1.36, 4.60] | 3.18 [1.58, 10.00] |
| joint_0.45_0.09 | 1.38 [0.78, 2.51] | 1.17 [0.58, 1.95] | 2.89 [1.77, 5.38] | 3.56 [2.02, 10.00] |
| det_joint_0.45_0.09 | 1.43 [0.82, 2.71] | 1.30 [0.59, 1.94] | 3.25 [2.16, 4.52] | 6.80 [2.60, 10.00] |

## 3. 单调性（新协议的核心结论）

| 模型 | σθ 序列 clean→0.1→0.45→0.5→1.0 | 单调下降 | σω 序列 clean→0.03→0.09→0.2 | 单调下降 |
|---|---|---|---|---|
| PINN | 1.48 → 1.43 → 1.38 → 1.39 → 1.15 | **否** | 1.48 → 1.40 → 1.35 → 1.18 | 是 |
| MLP_lam0 | 1.28 → 1.28 → 1.18 → 1.18 → 1.07 | 是 | 1.28 → 1.27 → 1.19 → 1.10 | 是 |
| Hybrid | 3.69 → 3.68 → 3.33 → 3.27 → 2.35 | 是 | 3.69 → 3.66 → 3.35 → 2.60 | 是 |
| Analytic | 10.00 → 10.00 → 4.69 → 4.24 → 2.47 | 是 | 10.00 → 10.00 → 6.55 → 3.12 | 是 |

## 4. 真实侧（29 段，lead=4s/pred=4s）

`median` 列 = 对**实测轨迹**的视界（h_real 同口径）；`vs_ideal` 列 = 对**同初值理想解析轨迹**的视界（§7.3 C_chaos 同口径）。

| 扰动档 | PINN (median / vs_ideal) | MLP_lam0 (median / vs_ideal) | Hybrid (median / vs_ideal) | Analytic (median / vs_ideal) |
|---|---|---|---|---|
| clean | 0.417 / 0.867 | 0.267 / 0.684 | 0.484 / 3.018 | 0.467 / 3.985 |
| th0.1 | 0.417 / 0.834 | 0.267 / 0.684 | 0.484 / 3.001 | 0.450 / 3.985 |
| th0.45 | 0.409 / 0.800 | 0.267 / 0.725 | 0.450 / 1.984 | 0.450 / 2.568 |
| th0.5 | 0.400 / 0.800 | 0.267 / 0.717 | 0.450 / 1.801 | 0.434 / 2.501 |
| th1.0 | 0.392 / 0.750 | 0.250 / 0.700 | 0.434 / 1.326 | 0.417 / 1.492 |
| w0.03 | 0.417 / 0.809 | 0.267 / 0.684 | 0.450 / 2.860 | 0.450 / 3.943 |
| w0.09 | 0.417 / 0.800 | 0.250 / 0.700 | 0.442 / 1.992 | 0.450 / 2.401 |
| w0.2 | 0.383 / 0.692 | 0.250 / 0.634 | 0.450 / 1.301 | 0.450 / 1.367 |
| joint_0.45_0.09 | 0.400 / 0.775 | 0.250 / 0.734 | 0.434 / 1.426 | 0.442 / 1.909 |
| det_joint_0.45_0.09 | 0.350 / 0.717 | 0.250 / 0.667 | 0.350 / 1.984 | 0.367 / 2.068 |

**与 §7.3 对表**：Analytic 模型 + 确定性 (+0.45°, +0.09 rad/s) 扰动、对理想轨迹的视界中位 = **2.068s**。§7.3 报的 C_chaos = 1.90s（rc/error_decomposition.py:157-160，用的是逐片实测 σθ/δω 而非全局 0.45/0.09），二者应同量级；若差得远说明口径没对上，要查。

## 5. 旧协议 vs 新协议

| 扰动档 | 旧协议(本复刻, PINN) | 新协议(PINN, 混沌子集) |
|---|---|---|
| 无扰动 | 5.84 | 1.48 |
| ±0.1° | 5.43 | 1.43 |
| ±0.5° | 3.50 | 1.39 |
| ±1.0° | 3.62 | 1.15 |

论文 tab:sensitivity 原值（`data/sensitivity/sensitivity_summary.csv`，只读引用）：±0.1°=3.59 / ±0.5°=3.34 / ±1.0°=3.66，参考 3.10s。
旧协议下模型看到的初值误差**逐位为 0**，详见 `old_protocol_diagnosis.txt`。

## 6. 对论文的影响

- main.tex:555-580 §6.2 整节 + tab:sensitivity 需按第 2 节的新表重写，结论由「初值稳健」改为「视界随初值不确定度单调塌缩」。
- main.tex:241-242 贡献 4 需改写：不再是「论证 ±0.5° 对结论的鲁棒性」，而是「量化初值估计精度对预测视界的定量代价」。
- main.tex:379 §4.2 末句「结论稳健」需一并改。
- 改写方向对论文有利：§6.2 与 §7.3（C_chaos=1.90s、可改进空间 1.5s）由互斥变互证，「1.5s 可改进空间来自初值估计精度」这句话第一次有了直接证据。
- 附录「方法论诚实性说明」可新增第四条：自查出旧敏感性协议把扰动逐位抵消并已改正。

## 7. 产物清单

- `insim_raw.csv` 仿真侧逐次评估原始记录
- `real_raw.csv` 真实侧逐次评估原始记录
- `summary.csv` 全部聚合（side × subset × model × level）
- `old_protocol_replication.csv` / `old_protocol_diagnosis.txt` 旧协议复刻与诊断
- `self_check.txt` 自证门槛完整输出
- `figures/horizon_vs_sigma_insim.png`, `figures/horizon_vs_sigma_real.png`, `figures/old_vs_new_protocol.png`

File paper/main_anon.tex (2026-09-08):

% =============================================================================
% ChaoticNet 物理竞赛论文 主文件
% 截稿：2026-09-15
% 编译：xelatex main.tex（中文需 xelatex，不要用 pdflatex）
% =============================================================================

\documentclass[a4paper,12pt]{ctexart}   % 正文小四（12pt），竞赛格式规范

% --- 数学 ---
\usepackage{amsmath, amssymb, amsthm}
\usepackage{bm}                                    % 粗体数学符号
\usepackage{physics}                               % \dv \pdv \abs 等

% --- 排版 ---
\usepackage[margin=2.5cm]{geometry}
\usepackage{setspace}
\setstretch{1.655}                       % 行距≈24磅（12pt 正文 baselineskip 14.5pt ×1.655）
\emergencystretch=3em                    % 小四下容差，消除不可断 \texttt/公式行的溢出
\usepackage{titlesec}
\usepackage{enumitem}

% --- 图表 ---
\usepackage{graphicx}
\graphicspath{{figures/}{../data/figures/}{../data/sim/figures/}{../data/real_validation/figures/}%
              {../data/v2_50trial_2026-06-11/}%
              {../data/sim/figures/v1_baseline_2026-06-11/}%
              {../data/rc/figures/v1_baseline_2026-06-11/}%
              {../data/pinn/figures/v1_baseline_2026-06-11/}}
\usepackage{booktabs}
\usepackage{caption}
\usepackage{float}
\usepackage{subcaption}

% --- 算法 / 代码 ---
\usepackage{algorithm}
\usepackage{algpseudocode}
\usepackage{listings}
\lstset{basicstyle=\ttfamily\small, breaklines=true, frame=single}

% --- 引用 ---
\usepackage[colorlinks=true, linkcolor=blue, citecolor=blue, urlcolor=blue]{hyperref}
\usepackage{cleveref}

% --- 文献 ---
% 参考文献采用 GB/T 7714—2015 顺序编码制；样式文件随项目放在 texstyles/gb7714/。
\usepackage[backend=biber, style=gb7714-2015, sorting=none]{biblatex}
\addbibresource{references.bib}
\let\cite\supercite   % 正文文献引用统一改为右上标数字

% --- 目录样式：章节页码统一为正常字号、不加粗（与子节一致；标题保留加粗以示层级）---
\makeatletter
\AtBeginDocument{%
  \renewcommand*\l@section[2]{%
    \ifnum \c@tocdepth >\z@
      \addpenalty\@secpenalty
      \addvspace{1.0em \@plus\p@}%
      \setlength\@tempdima{1.5em}%
      \begingroup
        \parindent \z@ \rightskip \@pnumwidth
        \parfillskip -\@pnumwidth
        \leavevmode \bfseries
        \advance\leftskip\@tempdima
        \hskip -\leftskip
        #1\nobreak\hfil
        \nobreak\hb@xt@\@pnumwidth{\hss \normalfont\mdseries #2%
                                   \kern-\p@\kern\p@}\par
      \endgroup
    \fi}%
}
\makeatother

% --- 自定义命令 ---
\newcommand{\tauL}{\tau_{\mathrm{L}}}              % Lyapunov 时间
\newcommand{\thetaone}{\theta_1}
\newcommand{\thetatwo}{\theta_2}

% --- 交叉引用中文名（cleveref 默认输出 section/figure/table，统一改为中文）---
\crefname{section}{节}{节}
\Crefname{section}{节}{节}
\crefname{subsection}{节}{节}
\Crefname{subsection}{节}{节}
\crefname{figure}{图}{图}
\Crefname{figure}{图}{图}
\crefname{table}{表}{表}
\Crefname{table}{表}{表}
\crefname{equation}{式}{式}
\Crefname{equation}{式}{式}
\crefname{algorithm}{算法}{算法}
\Crefname{algorithm}{算法}{算法}
\crefname{appendix}{附录}{附录}
\Crefname{appendix}{附录}{附录}

% --- 图表标题：比正文小一号 + 标签加粗，与正文区分 ---
\captionsetup{font={small,bf}}

% --- 正文强调不切换字形或字号，避免与普通正文产生视觉尺寸差异 ---
\renewcommand{\emph}[1]{#1}

% =============================================================================
\title{物理约束神经网络在双摆混沌预测中的应用\\
       \large 本科实验室级精度下的可信预测窗口扩展}
\author{}
\date{}

\begin{document}
\maketitle
\pagestyle{plain}   % 页码居中置于页脚，去除每页左上角的章节名页眉

% =============================================================================
\begin{abstract}
{\setlength{\parindent}{0pt}\setlength{\parskip}{0.8em}\setstretch{1.42}
双摆是经典的低维确定性混沌系统，其轨迹对初值极度敏感；传统观点认为，可信预测窗口通常不超过约一个 Lyapunov 时间（相邻轨迹偏离的特征时间）。本研究以双摆动力学为测试平台，把物理先验按由无到有、由弱到强分为四档，定量评估其在闭环递推预测任务中的表现：纯数据驱动的回声状态网络（Echo State Network, ESN）与多层感知机（multilayer perceptron, MLP）不含任何物理先验，物理约束神经网络（Physics-Informed Neural Network, PINN）以拉格朗日力学残差作为损失项弱约束，混合模型（Hybrid）则直接以解析运动方程为主干、仅用网络学习残差。所用数据来自本科实验室级硬件平台：双摆经手动释放，以 60\,fps 手机相机视觉追踪；初始角度与角速度由视觉追踪的轨迹反演获得，其中初始角度的估计不确定度约为 $0.5^\circ$。

在 50 组随机初值的仿真统计中（每个模型独立训练多次，取逐次运行中位数以反映训练随机性），
以物理结构由弱到强排列的三个模型，其中位可信预测视界（以角度欧氏偏差超过 $10^\circ$ 为阈值）
均超过纯数据驱动的 ESN 基线（0.70\,s，约 $0.91$ 个 Lyapunov 时间 $\tauL$，与文献给出的储池计算基线相符）：
解析先验最完整的混合模型（Hybrid）达 2.85\,s（$3.74\,\tauL$，约 4.1 倍），纯数据多层感知机（MLP）达 1.55\,s（$2.03\,\tauL$，2.2 倍），
带拉格朗日物理损失的 PINN 达 0.88\,s（$1.15\,\tauL$，1.3 倍）。更关键的是，在 29 段真实双摆视频上的零样本仿真到真实（sim$\to$real）迁移中，
物理先验模型仍显著占优——Hybrid 与 PINN 中位视界约为 ESN（0.167\,s）的 $2.5\text{--}2.7$ 倍。
物理损失恰在分布迁移下才显现价值：相同训练设置下，带物理损失（$\lambda_{\mathrm{phys}}=0.1$）
相对纯数据（$\lambda_{\mathrm{phys}}=0$）将真实中位视界由 0.36\,s 提升至 0.42\,s（约 $1.16\times$），
而这一增益在仿真内部并不出现（干净仿真数据上纯数据拟合反而更准）。我们进一步发现，sim$\to$real 迁移质量的首要决定因素是仿真保真度：采用与真实硬件一致的\emph{分布质量}摆模型，迁移质量显著优于理想点质量模型。为回答真实视界为何短于仿真内部值，我们用同口径的解析积分器隔离单一误差源，构造三条“天花板”作定量分解：实测视界 $0.42$\,s 远低于纯阻尼失配天花板（$1.35$\,s）与纯初值不确定天花板（$1.90$\,s），说明 $4$\,s 短窗内主导因素是模型逼近误差与初值估计误差的组合，而非无摩擦模型的阻尼失配——“修阻尼”在此无收益，提升初值测量精度才是方向。

高保真物理建模与物理约束可显著延长混沌预测窗口；物理损失在 sim$\to$real 迁移中尤具价值，
为低成本实验中的机器学习辅助动力学预测提供了可行路径。

\textbf{关键词：} 双摆；混沌；物理约束神经网络；回声状态网络；Lyapunov 时间
\par}
\end{abstract}

\begin{abstract}
{\setlength{\parindent}{0pt}\setlength{\parskip}{0.8em}
\textbf{Abstract.} The double pendulum is a classical low-dimensional
deterministic chaotic system. Conventional wisdom holds that trajectories can be reliably
predicted only within roughly one Lyapunov time.

We compare a purely data-driven Echo State Network (ESN)
against a Physics-Informed Neural Network (PINN) constrained by the Lagrangian equations of
motion, on closed-loop prediction of double-pendulum trajectories. All training data are
designed to match an undergraduate-lab-grade hardware platform:
manual pendulum release, a 60\,fps consumer-phone camera, and initial states recovered from
video tracking (estimation uncertainty $\approx 0.5^\circ$). We further implement a Hybrid (Universal-Differential-Equation
style) model fusing the analytical right-hand side with a small residual network, and report
results on both undamped and damped (fitted joint damping, $b \approx 1.66\times10^{-5}$\,N$\cdot$m$\cdot$s/rad) ground truth.

Across 50 random initial conditions, with each model trained
independently multiple times (reporting the median of per-run medians to reflect training
stochasticity), models carrying stronger physical structure outperform the data-driven ESN
(median horizon $0.70$\,s on chaotic trials, $10^\circ$ threshold): the fully-analytic-prior
Hybrid reaches $2.85$\,s ($\approx 4.1\times$), a pure-data MLP $1.55$\,s ($2.2\times$), and the
Lagrangian-physics-loss PINN $0.88$\,s ($1.3\times$). Normalized by the self-measured Lyapunov
time $\tauL = 0.76$\,s, these are $0.91/1.15/2.03/3.74\,\tauL$ for ESN/PINN/MLP/Hybrid, placing
our ESN baseline in line with the one-to-two Lyapunov times reported for reservoir computing.
Crucially, on 29 real double-pendulum videos under zero-shot sim$\to$real transfer,
physics-prior models retain a clear advantage (Hybrid and PINN median horizon
$\approx 2.5\text{--}2.7\times$ that of ESN, $0.167$\,s). The physics loss proves its worth
precisely under distribution shift: with identical training, $\lambda_{\mathrm{phys}}=0.1$
raises the real median horizon from $0.36$\,s ($\lambda_{\mathrm{phys}}=0$) to $0.42$\,s
($\approx 1.16\times$), a gain absent in-simulation, where clean-data fitting is most accurate.
We further find the dominant driver of sim$\to$real transfer is simulation fidelity: a
distributed-mass pendulum model matching the real hardware transfers markedly better than an
idealized point-mass model. A three-ceiling error decomposition shows the short real horizon is
governed primarily by the model's own approximation error, together with measurement noise and
initial-state uncertainty, rather than by the undamped model's damping mismatch.

High-fidelity physical modeling together with physics-informed
constraints substantially extend the trustworthy prediction window for chaotic systems in
low-cost experimental conditions, with the physics loss's value emerging precisely under
sim$\to$real distribution shift, providing a feasible pathway for ML-assisted dynamics
prediction on undergraduate-lab-grade hardware.

\textbf{Keywords:} double pendulum; chaos; physics-informed neural network;
echo state network; Lyapunov time
\par}
\end{abstract}

% =============================================================================
\newpage
{\hypersetup{linkcolor=black}\tableofcontents}
\newpage

% =============================================================================
\section{引言}
\label{sec:intro}

\subsection{研究背景}

混沌系统预测兼具理论深度与工程价值。大气是典型的高维混沌系统，数据驱动的天气预报模型 GraphCast 与盘古气象已在多数指标上超越传统数值预报系统，并能在分钟级时间内完成十天预报 \cite{lam2023graphcast,bi2023pangu}；而将物理定律作为先验约束嵌入学习模型的范式，也已在更广的工程与环境系统中得到系统性梳理 \cite{willard2022integrating}。

\paragraph{双摆混沌动力学}
双摆系统在 18 世纪被 Lagrange 系统研究，是最简单的能够呈现确定性混沌的二自由度
力学系统。Shinbrot 等人用照相法首次在实验上验证了双摆轨迹的
正 Lyapunov 指数特性 \cite{shinbrot1992}，Levien 与 Tan 设计了适用于
本科教学的双摆装置以演示其对初值的敏感依赖 \cite{levien1993pendulum}，Stachowiak 与 Okada
用谱方法系统刻画了相空间中混沌区与准周期区的边界 \cite{stachowiak2006chaotic}。Vitanov 等
计算了双摆在不同能量层级下的最大 Lyapunov 指数 $\lambda_{\max}$，
给出 Lyapunov 时间 $\tauL = 1 / \lambda_{\max}$ 的解析估算 \cite{vitanov2010lyapunov}。
混沌系统之所以难以长时间预测，根源在于初值的指数敏感性：
两条邻近轨迹的状态距离按 $e^{t / \tauL}$ 放大，无论初值精度多高，
可信预测都被限制在约 $1$ 个 Lyapunov 时间之内，这是混沌动力学的经典结论 \cite{ott2002}。

\paragraph{数据驱动预测：储池计算}
Echo State Network（ESN）由 Jaeger 与 Haas 提出，用稀疏随机
循环网络的“储池”提取高维非线性特征，仅训练线性读出层 \cite{jaeger2004}。
Lu 等与 Pathak 等系统研究了 ESN
在 Lorenz、Kuramoto-Sivashinsky 等混沌系统上的预测能力，给出“约 $1$--$2$ 个
Lyapunov 时间”的视界基线 \cite{lu2017reservoir,pathak2018}。ESN 不利用任何物理先验，纯靠时间序列学习。

\paragraph{物理约束与混合建模}
Raissi 等提出 Physics-Informed Neural Network（PINN），
将偏微分方程（partial differential equation, PDE）残差作为正则化项嵌入训练损失，使神经网络在求解 PDE 时遵守物理约束 \cite{raissi2019}。
针对哈密顿系统与拉格朗日系统，Greydanus 等提出 Hamiltonian
Neural Network（哈密顿神经网络，HNN）\cite{greydanus2019}，Cranmer 等提出 Lagrangian Neural
Network（拉格朗日神经网络，LNN）\cite{cranmer2020}；这两类模型通过学习系统的能量函数，在结构上保持能量守恒。
Karniadakis 等在 \textit{Nature Reviews Physics}
综述了该领域 \cite{karniadakis2021review}。
Chen 等提出的 Neural ODE（神经常微分方程）将动力学学习视为
连续时间常微分方程的求解 \cite{chen2018neuralode}，
Rackauckas 等进一步把已知物理方程与神经网络结合
为 Universal Differential Equation（通用微分方程，UDE）\cite{rackauckas2020universal}，即本文所称的 \emph{解析-NN 混合}范式。

\paragraph{本研究定位}
现有文献大多在数值仿真层面对比这些方法，鲜有在低成本实物装置（本科实验室级硬件、
手动释放、手机相机视觉测量与初值反演）下做端到端的可预测窗口量化。
本文聚焦这一空缺，并开源全套可复现材料：硬件加工图与物料清单（bill of materials, BOM）、
全部软件，以及 29 段真实轨迹的分析窗数据集与由原始录像重建逐帧结果的脚本
（详 \cref{sec:apparatus} 与 \cref{sec:appendix-reproducibility}）。
更重要的是，双摆在本文中被用作一个可\emph{精确开关物理先验}的最小试验台：在同一套数据与评测口径下，
把物理约束从无（纯数据 MLP）、到弱（物理损失 PINN）、再到强（解析先验 Hybrid）逐级注入，
使我们得以在受控条件下诚实回答\emph{物理约束何时有用、增益有多大}，而非停留在单一模型的点对比。

\subsection{研究问题}
\textbf{核心问题：} 在本科实验室级的测量精度下（相机 60\,fps、
初值状态估计不确定度约 $0.5^\circ$），为神经网络引入物理约束，能否显著延长它对混沌轨迹的可信预测窗口？

\subsection{本文贡献}
\begin{enumerate}[leftmargin=2em]
  \item 设计并实现了一套总成本约 580\,元的双摆实验装置（详 \cref{sec:apparatus}），
        设计目标为摆轴衰减时间常数 $\tau \geq 30$\,s，实测达 $\tau \approx 130$\,s（约 $4\times$ 目标，见 \cref{sec:apparatus}），以提供 AI 训练所需的“干净”混沌窗口；
  \item 对比 ESN、纯数据 MLP、PINN（拉格朗日物理损失）与 Hybrid（解析先验$+$残差）四类模型，
        在相同训练 / 预测设置、多次独立训练下量化物理结构的贡献；
  \item 揭示 sim$\to$real 零样本迁移的两个关键：仿真保真度（与真实硬件一致的\emph{分布质量}建模）
        为首要驱动，物理损失作为分布迁移下的稳健性正则提供二阶增益（在同分布仿真内反而无益）；
  \item 在初值不确定度上进行敏感性扫描（\cref{sec:results-sensitivity}），
        以解析真解为纯净参照，分离出混沌放大与模型逼近误差各自的贡献，
        并给出约 $\pm 0.5^\circ$ 初值不确定度下本研究结论的退化幅度。
\end{enumerate}

\subsection{论文结构}
\cref{sec:physics-model} 给出双摆拉格朗日动力学；\cref{sec:simulation} 介绍数值基线；
\cref{sec:apparatus} 描述硬件平台；\cref{sec:vision} 给出视觉追踪管线；
\cref{sec:ai-models} 介绍 ESN、Hybrid 与 PINN 三类模型；\cref{sec:results} 给出仿真内的对比结果与初值敏感性扫描；
\cref{sec:sim2real} 是本文的核心部分，报告 29 段真实轨迹上的零样本 sim$\to$real 迁移、
物理损失的价值边界，以及真实短视界的三天花板误差分解；\cref{sec:discussion} 讨论局限与展望；
\cref{sec:conclusion} 归纳结论。
附录中，\cref{sec:appendix-reproducibility} 给出完整的复现入口与目录结构，
\cref{sec:appendix-hyperparams} 列出各模型关键超参数，\cref{sec:appendix-ablation} 报告消融实验，
\cref{sec:appendix-honesty} 记录方法论上的自我修正。

% =============================================================================
\section{物理模型}
\label{sec:physics-model}

\subsection{拉格朗日方程}
双摆是非线性振动理论中的经典强耦合系统 \cite{nayfeh2008nonlinear}。
本研究的实物为\emph{分布质量}物理摆 \cite{rafat2009distmass}：上下摆杆是质量沿杆身分布的刚性铝臂，下摆末端另加配重，
质量并非集中于杆末端的理想质点。故以各摆的总质量 $M_i$、质心到其转轴的距离 $L_{c,i}$，
以及绕转轴的转动惯量建模——上摆绕固定顶轴 $O$ 的转动惯量记 $I_1^{O}$，
下摆绕关节轴 $A$ 的转动惯量记 $I_2^{A}$。设关节间距（顶轴到关节）为 $L_1$，
下摆几何长度为 $L_2$，两摆杆与竖直方向夹角分别为 $\thetaone, \thetatwo$（\cref{fig:pendulum-schematic}）。

\begin{figure}[htbp]
\centering

\caption{双摆物理模型示意图。两摆杆按分布质量刚体建模：$M_1, M_2$ 为各摆总质量，$L_{c1}, L_{c2}$ 为质心到相应转轴的距离，$L_1, L_2$ 为几何长度，$\thetaone, \thetatwo$ 为两摆与竖直方向的夹角，$g$ 为重力加速度。}
\label{fig:pendulum-schematic}
\end{figure}

拉格朗日量
\begin{equation}
\mathcal{L} = T - V
\label{eq:lagrangian}
\end{equation}
其中动能与势能为（下摆动能已用平行轴定理 $I_2^{A} = I_2^{\mathrm{cm}} + M_2 L_{c2}^2$ 合并）
\begin{align}
T &= \tfrac{1}{2}\left(I_1^{O} + M_2 L_1^2\right) \dot{\thetaone}^2
   + M_2 L_1 L_{c2} \cos(\thetaone - \thetatwo)\, \dot{\thetaone}\dot{\thetatwo}
   + \tfrac{1}{2} I_2^{A} \dot{\thetatwo}^2 \\
V &= -\left(M_1 L_{c1} + M_2 L_1\right) g \cos\thetaone - M_2 L_{c2}\, g \cos\thetatwo
\end{align}

\noindent 应用 Euler--Lagrange 方程
\[
\frac{d}{dt}\frac{\partial \mathcal{L}}{\partial \dot{\theta}_i}
- \frac{\partial \mathcal{L}}{\partial \theta_i} = 0
\]
得到运动方程的矩阵形式
\begin{equation}
\bm{M}(\bm{\theta}) \, \ddot{\bm{\theta}} = \bm{b}(\bm{\theta}, \dot{\bm{\theta}})
\label{eq:eom}
\end{equation}
其中质量矩阵与力向量为
\begin{align}
\bm{M}(\bm{\theta}) &= \begin{pmatrix}
  I_1^{O} + M_2 L_1^2 & M_2 L_1 L_{c2} \cos(\thetaone - \thetatwo) \\
  M_2 L_1 L_{c2} \cos(\thetaone - \thetatwo) & I_2^{A}
\end{pmatrix} \\
\bm{b}(\bm{\theta}, \dot{\bm{\theta}}) &= \begin{pmatrix}
  -M_2 L_1 L_{c2} \sin(\thetaone - \thetatwo) \dot{\thetatwo}^2 - (M_1 L_{c1} + M_2 L_1) g \sin\thetaone \\
   M_2 L_1 L_{c2} \sin(\thetaone - \thetatwo) \dot{\thetaone}^2 - M_2 L_{c2}\, g \sin\thetatwo
\end{pmatrix}
\end{align}
质量集中于杆末端的理想点质量摆是本式的特例
（$L_{c1}=L_1,\ L_{c2}=L_2,\ I_1^{O}=M_1 L_1^2,\ I_2^{A}=M_2 L_2^2$）。
本研究按实测物料清单（BOM，见 \texttt{diagrams/parts/BOM.md}）反推分布质量参数：
$L_1 = 250$\,mm, $L_2 = 200$\,mm，总质量 $M_1 \approx 96.5$\,g, $M_2 \approx 139$\,g，
质心距 $L_{c1} \approx 122$\,mm, $L_{c2} \approx 145$\,mm，转动惯量
$I_1^{O} \approx 1.99\times 10^{-3}\,\mathrm{kg\,m^2}$,
$I_2^{A} \approx 3.54\times 10^{-3}\,\mathrm{kg\,m^2}$，$g = 9.81$\,m/s$^2$。
采用与真实硬件一致的分布质量模型，是后文 sim$\to$real 零样本迁移得以成立的关键（见 \cref{sec:sim2real-decomp}）。
具体实现见 \texttt{sim/baseline.py}，符号求逆得到 $\ddot{\bm{\theta}} = \bm{M}^{-1} \bm{b}$。

\subsection{混沌特征：最大 Lyapunov 指数实测}
我们对 50 组随机初值（$\thetaone, \thetatwo \in [-90^\circ, 90^\circ]$ 均匀采样，
$\omega = 0$ 静止释放）实施基于轨迹分叉的最大 Lyapunov 指数估算：对每组参考初值
施加 $\varepsilon = 10^{-6}$\,rad 扰动，跟踪两条由 RK45（四/五阶 Runge--Kutta 自适应步长法）积分得到的轨迹之间的 4 维相空间欧氏距离
$d(t)$ 在 $3$\,s 内的指数增长，对数线性区拟合得到斜率 $\lambda_{\max}$。
50 组随机初值中 48 组有效拟合（另 2 组分叉斜率非正剔除）的分布（分布质量模型）：均值 $\bar\lambda_{\max} = 1.21$\,s$^{-1}$（$1/\bar\lambda_{\max} = 0.83$\,s），
中位 $\lambda_{\max}^{\mathrm{med}} = 1.31$\,s$^{-1}$（$\tauL^{\mathrm{med}} = 0.76$\,s）。
\emph{方法学注：} 此处 $\tauL = 0.76$\,s 取自分叉曲线 0.15--1.5\,s 区间的对数线性拟合，反映的是保守的短期分叉率而非严格的最大 Lyapunov 指数（后者需 Wolf 算法配合重整化跟踪到长时极限 \cite{vitanov2010lyapunov}）；本文仅以它作为归一化基准，物理先验模型相对 ESN 的提升这一核心结论并不依赖该值的绝对大小。
该结果显著低于文献在高能量混沌区给出的 $\lambda_{\max} \sim 5\text{--}10$\,s$^{-1}$
（$\tauL \sim 0.1\text{--}0.2$\,s）\cite{vitanov2010lyapunov}，但这种差异在物理上是合理的：本研究的静止释放对应较低
能量级，其局部 Lyapunov 指数较小；高能量区的文献数值适用于含初始角速度的高能轨迹。
本研究后文所有视界归一化均采用自测中位值 $\tauL = 0.76$\,s。

% =============================================================================
\section{数值仿真基线}
\label{sec:simulation}

\subsection{数值方法}
我们采用 SciPy \texttt{solve\_ivp} 中的 RK45 自适应步长积分器求解 \cref{eq:eom}，相对容差取 $10^{-10}$、绝对容差取 $10^{-12}$。为检验积分精度，我们对 50 组 30\,s 仿真进行能量守恒校核：总能量的最大相对漂移为 $8.8 \times 10^{-9}$、均值为 $7.0 \times 10^{-10}$，均处于机器精度量级。

\begin{figure}[h]
\centering

\caption{50 组 30\,s 仿真总能量相对漂移 $|E(t) - E_0| / |E_0|$，
最大值 $8.8 \times 10^{-9}$。RK45 + 严格容差下能量守恒在机器精度量级。}
\label{fig:energy-sweep}
\end{figure}

\subsection{蝴蝶效应可视化}
两条初值差 $0.1^\circ$ 的轨迹在前 3\,s 几乎重合，随后呈指数分叉
（\cref{fig:butterfly}）。这印证了 \cref{sec:intro} 提出的初值敏感性结论。

\begin{figure}[h]
\centering
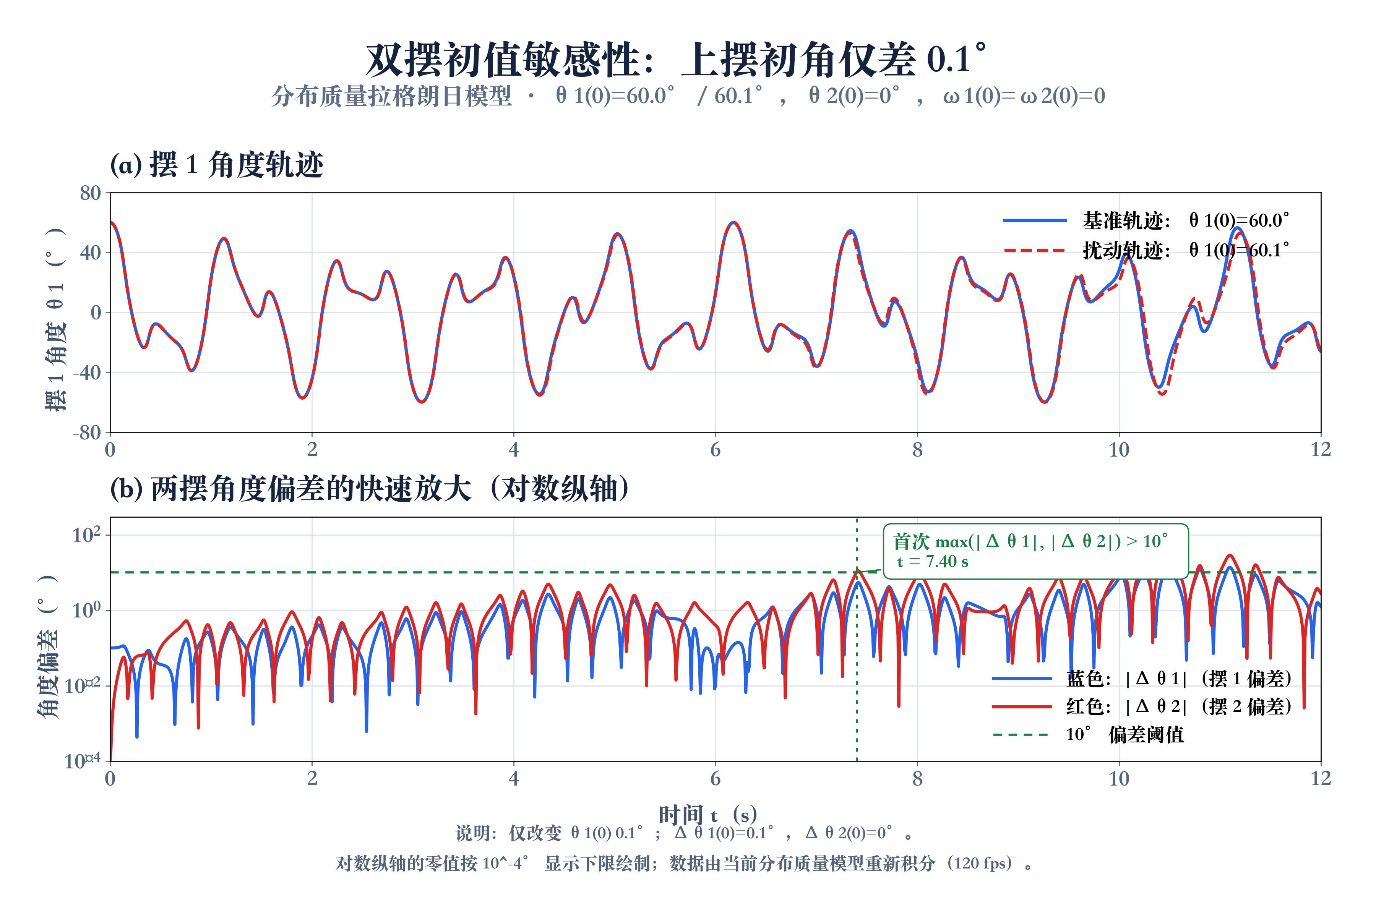
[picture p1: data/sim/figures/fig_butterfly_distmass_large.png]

\caption{蝴蝶效应（分布质量拉格朗日模型）：仅将 $\thetaone(0)$ 从 $60.0^\circ$ 改为 $60.1^\circ$，其余初值均保持 $\thetatwo(0)=0^\circ$、$\omega_1(0)=\omega_2(0)=0$。
(a) 两条 $\thetaone$ 轨迹前期几乎重合，随后分叉；(b) 分别给出两摆角度偏差的绝对值（对数纵轴）。初始时 $|\Delta\theta_1|=0.1^\circ$、$|\Delta\theta_2|=0^\circ$；后者的零值以 $10^{-4}\,{}^\circ$ 的显示下限绘制。首次满足 $\max(|\Delta\theta_1|,|\Delta\theta_2|)>10^\circ$ 的时刻为 $7.40\,$s。}
\label{fig:butterfly}
\end{figure}

% =============================================================================
\section{实验装置}
\label{sec:apparatus}

\subsection{机械设计}
装置正视装配图见仓库 \texttt{diagrams/02\_mechanical\_front\_view.svg}，
关键尺寸与材料：
\begin{itemize}[leftmargin=2em]
  \item 摆长：$L_1 = 250$\,mm，$L_2 = 200$\,mm（非对称避免简正模退化）
  \item 摆臂：6061-T6 铝板，$4$\,mm 厚（匹配 MR105ZZ 轴承宽度 4\,mm）
  \item 主轴承：MR105ZZ 微型深沟球轴承，工业酒精脱脂去除厂润滑脂，单滴 MOEBIUS 9020 钟表油重新润滑
  \item 配重盘：45\# 碳钢 $\varnothing 30 \times 12$\,mm，$66$\,g
  \item 主轴座：6061-T6 5\,mm 厚，$\varnothing 5$ H7 轴孔 + 2 个 M5 安装孔
  \item 框架：$2020$ 国标铝型材，T 槽螺母拼接
\end{itemize}
材料 + 加工件 + 视觉件总采购成本约 580 元（详 \texttt{diagrams/parts/BOM.md}）；
其中背板与标记两项视觉件按设计方案计入，实拍 29 段实际采用的是更易得的替代方案（见 \cref{sec:vision}）。

\subsection{初值设定与不确定度}
本研究的真实轨迹由手动将下摆抬至目标角度后释放产生，释放角度不作精确机械控制。
关键在于：每段真实轨迹输入模型的初始状态 $(\thetaone, \thetatwo, \omega_1, \omega_2)$ 并非取自释放动作的标称角度，
而是由视觉追踪从释放后的引入窗中反演得到（见 \cref{sec:vision} 与 \cref{sec:sim2real-horizon}）。
因此模型预测所依赖的是\emph{初始状态的视觉估计精度}，而非释放动作的机械重复性——
手动释放引入的微小初始角速度也被追踪如实捕获，一并纳入初始状态。
\cref{sec:sim2real-decomp} 的误差分解实测该初值状态估计噪声为角度 $\sigma_\theta \approx 0.45^\circ$、
角速度 $\delta\omega \approx 0.09$\,rad/s，约相当于 $\pm 0.5^\circ$ 量级；
该不确定度对预测视界的影响经敏感性扫描（\cref{sec:results-sensitivity}）量化：
在该量级下 PINN 中位视界退化约 $10\%$，本文结论不受影响。

\subsection{衰减测试}
为保证机器学习训练所需的“干净”混沌窗口，装置主轴承应满足单摆 $30^\circ$ 释放衰减时间常数
$\tau \geq 30$\,s。脱脂 + 钟表油润滑方案的衰减指标由下文实物测试直接验证。
实物衰减测试已完成：单摆 $90^\circ$ 释放、重复两次，振幅自 $90^\circ$ 衰减至约 $1\text{--}2^\circ$ 历时约 $551$\,s（两次分别 $552.0$ / $550.8$\,s，重复性 $0.2\%$）；按指数包络 $A(t) = A_0 e^{-t/\tau}$ 估算等效衰减时间常数 $\tau \approx 130$\,s（随终止振幅取值在 $122\text{--}145$\,s 区间），约为设计目标的 $4$ 倍，满足 $\tau \geq 30$\,s（实测在 $90^\circ$ 大幅释放下进行、含较强空气阻力，相对 $30^\circ$ 设计口径为保守下界，$30^\circ$ 释放的 $\tau$ 只会更大）。该等效 $\tau$ 对应单摆主轴承等效粘性 $b \approx 2 I_{\mathrm{eff}} / \tau \approx 1.7 \times 10^{-4}$\,N$\cdot$m$\cdot$s/rad（手计时等效估计，$90^\circ$ 大幅释放含较强空气阻力，为保守上界）。\emph{双摆运行工况}下的关节阻尼则另由 16 段实测追踪轨迹按能量耗散率法拟合（\texttt{sim/fit\_damping.py}，详见 \cref{sec:sim2real-decomp}），分离为粘性 $b \approx 1.66 \times 10^{-5}$ 与二次空气阻力 $c \approx 8.72 \times 10^{-6}$（空气阻力约占总耗散 $78\%$，逐段 $R^2$ 实测在 $0.95\text{–}0.999$ 区间、中位 $0.986$，见 \texttt{data/sim\_damped/fit\_damping\_report.csv}）。
对单摆等效转动惯量 $I_{\mathrm{eff}} \approx 1.1 \times 10^{-2}$\,kg$\cdot$m$^2$，
$\tau \geq 30$\,s 目标对应阻尼系数上界 $b \leq 2 I_{\mathrm{eff}} / (30\,\text{s}) \approx 7 \times 10^{-4}$\,N$\cdot$m$\cdot$s/rad（实测等效 $b \approx 1.7 \times 10^{-4}$ 在此上界之内）。
我们在 \texttt{sim/baseline\_damped.py} 中实现了带粘性 + 二次空气阻力两项的仿真版本作为 \emph{v3 真值}，
默认即采用上述实测拟合系数 $b \approx 1.66 \times 10^{-5}$、$c \approx 8.72 \times 10^{-6}$（不再用占位值），亦可经命令行参数覆盖。

% =============================================================================
\section{视觉测量系统}
\label{sec:vision}

\subsection{相机配置}
采用消费级智能手机后置摄像头以 $60$\,fps 拍摄（数据集统一采用 60\,fps 长时连续录像；
机型亦支持 120\,fps 慢动作，仅用于早期测试，未纳入分析数据集）。
本装置下摆的小摆动频率按点质量近似为 $\sqrt{g / L_2}/2\pi \approx 1.1$\,Hz；混沌大幅甩动下的瞬时角速率远高于此。
由 29 段正式追踪结果（\texttt{data/tracking/tracked\_*.csv}，共 $411\,746$ 帧）回算，
$\max(|\omega_1|, |\omega_2|)$ 的全库峰值为 $25.8$\,rad/s，折合 $4.11$\,Hz；
逐段峰值的中位为 $3.19$\,Hz，折合频率超过 $3.2$\,Hz 的帧仅占 $0.04\%$。
以实测全库峰值 $4.11$\,Hz 计，$60$\,fps 约为 $15$ 倍过采样（相对 $8.2$\,Hz 的 Nyquist 采样下限约为 $7$ 倍）；
该峰值处单帧角度增量约 $24.7^\circ$，远小于相位解卷绕失效所需的 $180^\circ$，采样充分。
相机固定于三脚架，光轴近似垂直于摆动平面，录制分辨率 $1920 \times 1080$；
由标定内参（$f_x / W \approx 0.81$，水平视场角约 $63^\circ$）与下述像素标度反推，工作距离约 $0.9$\,m。
以正式 29 段追踪结果中 $m_1$--$m_2$ 像素间距的中位（$353$\,px）对下摆长 $L_2 = 200$\,mm 定标，
得有效像素标度约 $0.57$\,mm/px，对应视野约 $1.1 \times 0.6$\,m。

\subsection{追踪算法}
上下摆铰接处与下摆末端各贴一枚方形彩色贴片作为视觉标记：铰接处记 $m_1$（蓝色），末端记 $m_2$（浅红色）；
两枚标记在实拍打光下均无镜面高光，末端标记成像偏粉、饱和度偏低。
正式 29 段中 $m_1$、$m_2$ 的连通域面积中位分别约 $370$ 与 $650$\,px，按上述 $0.57$\,mm/px 折合等效直径约 $12$ 与 $16$\,mm。
拍摄背景为置于摆后方的深色织物，画面两侧仍可见浅色墙面。
\texttt{diagrams/parts/BOM.md} 中列出的哑光黑亚克力背板与 $\varnothing 5$\,mm 反光圆点标记属装置设计方案，
本文 29 段实测录像未采用，正文各处均以上述实拍状态为准。
实拍追踪管线（\texttt{tracking/track\_pendulum.py}）流程：
\begin{enumerate}[leftmargin=2em]
  \item 帧 BGR 色彩通道（蓝、绿、红）$\to$ HSV 色彩空间（色相、饱和度、明度）
  \item 红色区间 + 蓝色区间各自做 \texttt{inRange} 阈值分割（红色由于跨越 H=0$^\circ$ 用双段并集）
  \item 形态学开 + 闭运算（半径 5 的椭圆核）去噪
  \item \texttt{connectedComponentsWithStats} 取全部面积超过 \texttt{MIN\_AREA} 的连通域作为候选
        （合成视频验证脚本 \texttt{track.py} 在此直接取最大连通域）
  \item 像素轨迹 $\to$ 物理坐标（自动标定：$m_1$ 轨迹最小二乘拟合圆得支点与 $L_1$ 像素半径）
  \item 反解角度：$\thetaone = \mathrm{atan2}(x_1, -y_1)$，$\thetatwo = \mathrm{atan2}(\Delta x, -\Delta y)$
\end{enumerate}
保留全部候选、再交由双向 Viterbi 选轨，是本管线与逐帧取最大连通域这一常见做法的主要差别。实拍画面中的同色干扰并不罕见：作为背景的深色织物在相机中成像偏藏青、色相落入蓝色区间——若仅把明度门限退回脚本默认（\texttt{-{}-blue-vmin 40}，饱和度与空间门限仍取正式参数），$29$ 段每帧的蓝候选中位便涨到 $27\text{--}76$ 个（全库中位 $41$ 个，其中 IMG\_1448 段为 $46$ 个，与下文消融一致；逐段统计见 \texttt{tools/count\_blue\_candidates.py}，结果落盘于 \texttt{data/tracking\_ablation/}），织物褶皱与底边缝线处尤其容易形成不随摆动移动的常驻斑点，面积有时还大于真标记；暖色墙面与释放瞬间入镜的手则会落进红色阈值。其中个别干扰恰好还位于距末端标记约 $\ell$ 处——此时仅凭刚性距离无从判别。我们在 IMG\_1448 段（$13\,153$ 帧）上对选轨策略做了消融（\texttt{tools/ablation\_transition\_cost.py}，两种策略共用同一批检测候选，差别仅在转移代价系数）：沿用脚本默认的低明度门限时，每帧蓝候选中位达 $46$ 个（最多 $67$ 个），只用刚性距离约束有 $9\,123$ 帧（$69\%$）选到与联合判别不同的候选，$m_1$ 圆拟合 RMS 残差为 $133$\,px；补上帧间位移的转移代价后残差降至 $43$\,px。但二者均远超下文 $10$\,px 的合理性门槛，说明时序连续性能大幅压制同色假阳性、却并不能挽救一个取错的阈值——这正是本管线在阈值标定之外还要设硬性合理性检查的原因。而在抬高明度门限后的正式参数下，每帧蓝候选中位降至 $1$ 个、仅 $9$ 帧出现多候选，两种策略选出的轨迹完全一致（RMS 均为 $0.42$\,px），此时刚性约束已单独够用。可见转移代价的价值随假阳性密度而变，两条准则联合使用才能在参数偏离时仍保持鲁棒。

阈值随场景标定：正式数据集 29 段共用同一套 HSV 阈值（蓝色明度门限 $V \geq 160$、饱和度门限 $S \geq 55$ 与右侧空间门限），仅时间窗逐段不同；抬高蓝色明度门限正是为了把偏藏青的背景与实测明度约 $240$ 的高亮蓝标分开。阈值取错时管线不会报错，而会给出自洽却错误的结果（命中率与帧间平滑度等内建指标仍全部正常，支点却被拟合到画面之外），故在写出结果前设三项硬性合理性检查：支点须落在画面内、圆拟合 RMS 残差须 $\leq 10$\,px、$\ell / r$ 须落在设计值 $L_2 / L_1 = 0.80$ 的 $\pm 25\%$ 以内，任一不满足即拒绝写盘。29 段的完整复现命令留档于 \texttt{tracking/reproduce\_29.sh}，据此重跑所得 CSV 与本文所用追踪结果逐字节一致（已抽取其中 5 段核对 MD5）。脚本另备一条 Lab 色彩空间的检测分支（\texttt{-{}-detector lab}）以适配不同配色的标记，本文 29 段数据全部采用上述 HSV 分支。

角度定义与几何反演的精度在 \texttt{data/sim/figures/anim\_trial\_000.mp4}（30\,fps 合成动画，真值已知）上验证——该合成片段由 \texttt{tracking/track.py} 追踪，与实拍脚本共用同一套角度定义与自动标定几何——跟踪角度中位误差
$\thetaone : 0.12^\circ$, $\thetatwo : 0.15^\circ$，$90\%$ 分位误差 $0.25\text{--}0.35^\circ$。
该结果表明追踪算法在干净图像上误差极小；真实拍摄下初值状态的估计噪声更高（约 $0.45^\circ$，见 \cref{sec:sim2real-decomp}），主要来自实拍光照、反光与运动模糊，构成真实视界的主要可改进来源之一。

\subsection{标定与精度}
相机内参用 OpenCV 的 \texttt{calibrateCamera} \cite{bradski2000}（基于 Zhang 平面标定法 \cite{zhang2000}）在 7$\times$9 棋盘格上标定。
仓库内存有两套标定：29 段 canonical 追踪结果由 \texttt{camera\_params.npz}（五参畸变模型）产出，
这也是 \texttt{tracking/track\_pendulum.py} 默认加载的标定；此外还有一次后做的重标定
\texttt{camera\_params\_新标定.npz}（14 张有效标定图，固定 $k_3 = 0$ 的四参模型，平均重投影误差 $0.44$\,px），
未用于产出本文数据。为确认结论不依赖标定的选取，我们把两套标定分别作用于 29 段的标记点轨迹并反演角度
（\texttt{tools/calib\_sensitivity.py}）：扣除两者主点差异造成的整体常数偏置后，
逐帧角度残差的逐段中位为 $\thetaone\,0.10^\circ$、$\thetatwo\,0.22^\circ$，
均小于约 $\pm 0.5^\circ$ 的初值状态估计不确定度（\cref{sec:sim2real-decomp}），故标定选取对本文结论无实质影响。
摆的运动平面与相机光轴近似垂直，且角度反演只取像素差的比值、与整体像素标度无关，
因此无须把像素轨迹换算为米制即可得到角度。实测亦支持这一处理：29 段中 $m_1$--$m_2$ 像素间距在整段内的
相对波动（标准差/中位）中位为 $1.2\%$、最大 $1.6\%$，说明投影标度全程近似恒定，
面外运动与透视效应造成的标度变化处于同一量级。

% =============================================================================
\section{机器学习模型}
\label{sec:ai-models}

\subsection{回声状态网络（ESN）基线}
\label{sec:esn}
ESN 的核心思想是用稀疏随机循环网络（“储池”）将输入投影到高维非线性
特征空间，仅训练线性读出层 \cite{jaeger2004}。本研究 ESN 配置：
\begin{itemize}[leftmargin=2em]
  \item 储池规模 $N_{\mathrm{res}} = 800$
  \item 谱半径 $\rho(\bm{W}) = 0.95$（接近临界，满足回声状态性质）
  \item 漏率 $= 0.25$，稀疏度 $0.1$
  \item 输入编码：状态 $(\thetaone, \omega_1, \thetatwo, \omega_2)$ 映射为
        $(\sin\thetaone, \cos\thetaone, \omega_1 / 10, \sin\thetatwo, \cos\thetatwo, \omega_2 / 10)$
        6 维向量
  \item 读出层用岭回归 $\alpha = 10^{-5}$ 求解，washout 200 步
\end{itemize}
\noindent 上述为仿真侧配置。真实数据侧每段仅有 $4$\,s 引入窗可供自训练，
为避免小样本下的过拟合，ESN 基线改用规模更小的储池（$N_{\mathrm{res}} = 300$、漏率 $0.3$、
$\alpha = 10^{-3}$、washout $50$，见 \texttt{rc/real\_validation\_multi.py}）。
为排除“人为削弱基线”的疑虑，我们把上述仿真侧配置连同一个四因子超参网格
（储池规模、谱半径、漏率、岭系数）同样在 29 段真实数据上完整跑过一遍
（\texttt{tools/esn\_grid\_real.py}，结果见 \texttt{data/esn\_grid\_real/summary.md}）：
在本文所用的 $4$\,s 引入窗下，仿真侧配置给出的 ESN 中位视界为 $\ge 0.167$\,s、
网格最优配置为 $\ge 0.183$\,s（“$\ge$”因部分片段右删失，中位为下界），
均仍显著低于同一单次运行口径下的 PINN $0.417$\,s 与 Hybrid $0.484$\,s
（seed 42，\texttt{data/real\_validation/summary\_multi.csv}；\cref{tab:real-horizon} 报的是 8 次独立重训的逐次运行中位）；
作为同口径参照，真实侧配置本身在该网格下为 $\ge 0.150$\,s。可见本文结论不依赖 ESN 配置的选取。

\paragraph{物理先验的优势边界：引入窗越长，纯数据基线越强} 同一份网格扫描还沿引入窗长度
$T_{\mathrm{lead}} \in \{2, 4, 8, 16, 32\}$\,s 做了二维展开，回答一个自然的追问——
纯数据 ESN 需要每段多少秒实测数据现场自训练，才能追平一秒真实数据都不用的零样本物理模型。
在预测窗同为 $4$\,s 的口径下，网格最优 ESN 的中位视界随 $T_{\mathrm{lead}}$ 由 $0.150$\,s（$2$\,s）
增至 $\ge 0.183$（$4$\,s）、$\ge 0.534$（$8$\,s）、$\ge 1.234$（$16$\,s）、$\ge 3.735$\,s（$32$\,s），
而 Hybrid 相应为 $0.600 / 0.484 / 0.717 / 1.000 / 1.267$\,s：
在本文所用的 $4$\,s 引入窗下物理先验占优约 $2.6$ 倍，$T_{\mathrm{lead}} = 16$\,s 附近纯数据基线反超，
$32$\,s 时已明显领先。我们如实报告这一交叉，并据此把本文的结论限定在其成立的条件上：
\emph{物理先验的价值出现在真实数据稀缺的一侧}——每段只有数秒可用历史时，
把已知方程放进模型远比让网络从这几秒里学动力学更有效；一旦每段可获得数十秒的实测数据，
纯数据方法自会追上并超过。这正是低成本、短录制场景（也是本文的目标设定）最关心的区间。
需说明的是，长引入窗档的中位数受右删失影响较大（$T_{\mathrm{lead}} = 32$\,s 时删失率达 $48\%$），
其数值为下界，故上述交叉点的位置只宜作量级判断。逐档完整结果见 \texttt{data/esn\_grid\_real/summary.md}。
完整实现见 \texttt{rc/esn.py}（约 290 行）。

\subsection{物理-数据混合模型（Hybrid）}
\label{sec:hybrid}
为评估“已知物理 + NN 残差”范式在本任务上的价值，我们实现了
Universal Differential Equation 风格的 Hybrid 模型 \cite{rackauckas2020universal}：
\begin{equation}
\dot{\bm{\omega}}_{\mathrm{Hybrid}}(\bm{\theta}, \bm{\omega})
= \dot{\bm{\omega}}_{\mathrm{baseline}}(\bm{\theta}, \bm{\omega}) + s \cdot \mathrm{MLP}(\bm{\theta}, \bm{\omega})
\label{eq:hybrid}
\end{equation}
其中 $\dot{\bm{\omega}}_{\mathrm{baseline}}$ 为 \cref{eq:eom} 给出的解析方程右端项（right-hand side, RHS），
$s$ 为残差缩放因子。MLP 末层权重采用 \texttt{xavier\_normal} 初始化（$\mathrm{gain}=0.01$），并取很小的初始幅度，
保证初始预测约等于解析先验。Hybrid 的训练损失与 PINN 同构（\cref{eq:pinn-loss}），
同为数据项与拉格朗日物理残差项的加权和，取 $\lambda_{\mathrm{phys}} = 0.5$、配点数 $1024$、
batch $512$、Adam 学习率 $1 \times 10^{-3}$ 配余弦衰减，训练 $200$ epoch。
因解析先验已承担右端项的主体，网络只需学一个很小的残差，物理残差项在训练早期即接近零；
该权重在此的作用是约束残差不把解推离物理可行流形，而非像 PINN 那样承担物理信息的主要注入。
完整实现见 \texttt{rc/hybrid.py}。

\subsection{物理约束神经网络（PINN）}
\label{sec:pinn}

\paragraph{网络结构} MLP，6 维输入 $\to$ 128 单元 $\times 4$ 隐层 $\to$ 2 维输出（$\dot\omega_1, \dot\omega_2$）。
输入采用极坐标编码 $(\sin\theta_i, \cos\theta_i, \omega_i / W_{\text{scale}})$，
输出归一化 $\dot\omega / A_{\text{scale}}$，其中 $W_{\text{scale}} = 10$，$A_{\text{scale}} = 100$。

\paragraph{损失函数} 数据项 + 物理项的加权和
\begin{equation}
\mathcal{L} = \mathcal{L}_{\text{data}} + \lambda_{\text{phys}} \, \mathcal{L}_{\text{phys}}
\label{eq:pinn-loss}
\end{equation}
其中物理残差直接从 \cref{eq:eom} 推出
\begin{equation}
\mathcal{L}_{\text{phys}} = \left\| \bm{M}(\bm{\theta}_c) \, \dot{\bm{\omega}}_{\text{NN}}(\bm{\theta}_c, \bm{\omega}_c)
- \bm{b}(\bm{\theta}_c, \bm{\omega}_c) \right\|^2
\end{equation}
每个 epoch 均重新采样 2048 个配点（即用于计算物理残差的状态点）$(\bm{\theta}_c, \bm{\omega}_c)$。

\paragraph{训练} 训练 300 个 epoch（完整遍历训练集的轮次），采用 Adam（自适应矩估计）优化器，初始学习率为 $2 \times 10^{-3}$，并使用余弦衰减。
\cref{alg:pinn-train} 给出完整训练流程。

\begin{algorithm}[h]
\caption{PINN 训练循环（rc/pinn.py 实现）}
\label{alg:pinn-train}
\begin{algorithmic}[1]
\Require 训练数据 $\{(\bm{s}^{(i)}, \dot{\bm{\omega}}^{(i)})\}_{i=1}^N$（来自 trial 0-4 前 20\,s）
\Require 网络 $f_\phi : \mathbb{R}^4 \to \mathbb{R}^2$，损失权重 $\lambda_{\mathrm{phys}}$，配点数 $N_c$
\Ensure 训练后的网络参数 $\phi^*$
\For{epoch $= 1$ \textbf{to} $300$}
  \For{每个 mini-batch $\mathcal{B}$（batch size 512）}
    \State 从训练集采样 $(\bm{s}_b, \dot{\bm{\omega}}_b) \in \mathcal{B}$
    \State 从相空间 $\bm{\theta} \in [-\pi, \pi]^2,\ \omega_1 \in [-20, 20],\ \omega_2 \in [-25, 25]$ 均匀采样 $N_c = 2048$ 个配点 $\{\bm{s}_c\}$
    \State $\dot{\bm{\omega}}_b^{\mathrm{pred}} \gets f_\phi(\bm{s}_b)$；\quad $\dot{\bm{\omega}}_c^{\mathrm{pred}} \gets f_\phi(\bm{s}_c)$
    \State $\mathcal{L}_{\mathrm{data}} \gets \| (\dot{\bm{\omega}}_b^{\mathrm{pred}} - \dot{\bm{\omega}}_b) / A_{\mathrm{scale}} \|^2$
    \State $\mathcal{L}_{\mathrm{phys}} \gets \| \bm{M}(\bm{\theta}_c) \, \dot{\bm{\omega}}_c^{\mathrm{pred}} - \bm{b}(\bm{\theta}_c, \bm{\omega}_c) \|^2$
    \State $\mathcal{L} \gets \mathcal{L}_{\mathrm{data}} + \lambda_{\mathrm{phys}} \cdot \mathcal{L}_{\mathrm{phys}}$
    \State $\phi \gets \mathrm{Adam}(\phi, \nabla_\phi \mathcal{L})$
  \EndFor
  \State 更新余弦学习率
\EndFor
\State \Return $\phi$
\end{algorithmic}
\end{algorithm}

\paragraph{闭环预测} 用 RK4（四阶 Runge--Kutta 法）积分 $\dot{\bm{s}} = [\omega_1, \dot\omega_1, \omega_2, \dot\omega_2]$，
$\dot{\bm{\omega}}$ 由训练好的 $f_{\phi^*}$ 给出，时间步 $\Delta t = 1/120$\,s。

% =============================================================================
\section{结果与分析}
\label{sec:results}

\subsection{评测协议}
\label{sec:results-protocol}
全文以\emph{可信预测视界}为唯一评测指标，定义为闭环预测的角度偏差首次超过阈值的时刻
\begin{equation}
h = \min\left\{ t \;:\; \sqrt{\Delta\thetaone(t)^2 + \Delta\thetatwo(t)^2} > 10^\circ \right\},
\quad
\Delta\theta_i = \mathrm{atan2}\!\left(\sin\delta_i,\, \cos\delta_i\right),\;
\delta_i = \hat\theta_i - \theta_i
\label{eq:horizon}
\end{equation}
其中 $\hat\theta_i$ 为预测角，$\theta_i$ 为解析积分或视觉追踪给出的真值角；$\mathrm{atan2}$ 形式用于消除角度的
$2\pi$ 周期歧义。若整个评估窗内偏差始终不超阈，则记视界为窗长并标注为\emph{右删失}，该值为真实视界的下界。
仿真内与真实数据两侧共用同一实现，仅评估窗长不同（仿真 $10$\,s、真实 $4$\,s）。
\cref{fig:butterfly} 的蝴蝶效应示意为便于逐轴读图另用 $\max(|\Delta\thetaone|, |\Delta\thetatwo|) > 10^\circ$ 判据，
其 $7.40$\,s 与本节各表不属同一口径，不作横向比较。$10^\circ$ 阈值本身的稳健性核验见 \cref{sec:appendix-honesty}。

\subsection{可信预测视界}
\label{sec:results-horizon}

仿真内的训练与评测按如下口径划分：PINN、纯数据 MLP 与 Hybrid 三者仅以 trial 0--4 前 $20$\,s 的
状态与加速度样本训练一次，随后在全部 50 组随机初值（trial 0--49）第 $20$\,s 处以真值状态为起点闭环外推 $10$\,s，
其中 45 组为训练中未出现过的轨迹；ESN 则是逐段自训练的时序模型，对每个 trial 单独以其前 $20$\,s
训练读出层，再预测同一 trial 随后的 $10$\,s。此口径对 ESN 有利——它拿到的是待预测轨迹本身的历史，
而三个网络模型只拿到一个初始状态；物理先验模型在此不利口径下仍占优。
需说明的是，trial 0--4 的预测段虽与其训练段在时间上不重叠，但仍取自训练所用的同一批轨迹，
故 50 组评测中有 5 组并非严格的样本外评估。
每个模型均在自身的混沌子集（视界 $< 9.9$\,s）上取中位数，以排除少数落入或被预测为长周期轨道的试验样本（trial）；
其中三方模型（ESN / PINN / Hybrid）一致判定为混沌的样本共 $N = 32$（\cref{fig:three-way} 所用子集）。
统计结果列于 \cref{tab:horizon-compare}。

\begin{table}[h]
\centering
\caption{50 组完整扫描 · 混沌 trial（每次运行取视界 $< 9.9$\,s 子集）闭环预测视界统计（$10^\circ$ 阈值）。
每个模型独立训练多次（ESN 更换储池随机种子 $\times 10$；PINN/Hybrid 非确定性重训 $\times 8$），报告逐次运行中位的中位数及四分位距 [IQR]。}
\label{tab:horizon-compare}
\begin{tabular}{lcccc}
\toprule
模型 & 视界中位 (s) & IQR (s) & 归一化 $/\tauL$ & 相对 ESN \\
\midrule
ESN（数据驱动基线）            & 0.70 & [0.55,\,0.70] & 0.91 & 1.0$\times$ \\
PINN（$\lambda_{\text{phys}}{=}0.1$） & 0.88 & [0.77,\,1.03] & 1.15 & 1.3$\times$ \\
纯数据 MLP（$\lambda_{\text{phys}}{=}0$，消融） & 1.55 & [1.31,\,1.68] & 2.03 & 2.2$\times$ \\
Hybrid（解析先验$+$残差）       & 2.85 & [2.12,\,3.27] & 3.74 & 4.1$\times$ \\
\bottomrule
\end{tabular}
\\[1em]
\footnotesize 倍数为各模型逐次运行中位数之比。Hybrid 与纯数据 MLP 明显超过数据驱动的 ESN 基线，
PINN 亦高于 ESN 但幅度有限；其中解析先验最完整的 Hybrid 在仿真内最强。
带物理损失的 PINN（$\lambda{=}0.1$）仿真内中位（0.88\,s）低于无物理损失的纯数据 MLP（1.55\,s）——
在干净、无噪的仿真数据上纯数据拟合本就最准，物理损失在此略有代价；其真正价值体现在
sim$\to$real 零样本迁移（见 \cref{sec:sim2real-decomp}）。
\emph{ESN 行取修正后的值}：早先的闭环实现中，预测入口的储池起跑点与训练契约相差一个储池步——
训练时状态 $\bm{X}[t]$ 已消费输入 $\bm{U}[t]$，而闭环入口又把该帧重喂了一次——
致使 ESN 在预测窗第 $0$ 帧即带约 $2^\circ$ 的角度偏差（修正后降至 $10^{-3}$ 度量级），
中位视界被压至 $0.40$\,s。按训练契约对齐起跑点后 ESN 升至 $0.70$\,s，
相对倍数相应由 $2.2 / 3.8 / 7.0$ 修正为 $1.3 / 2.2 / 4.1$。
新旧实现的逐位等价验证与逐 trial 对照见 \texttt{tools/esn\_closedloop\_fix.py}。
真实侧的 ESN 调用本就与训练契约一致，\cref{tab:real-horizon} 的数字不受影响。
\end{table}

\noindent 以自测 $\tauL = 0.76$\,s 归一化，纯数据驱动的 ESN 可维持约 $0.91\,\tauL$ 的可信预测——
这与文献给出的“约 $1$--$2$ 个 Lyapunov 时间”的储池计算基线相符 \cite{lu2017reservoir,pathak2018}，
表明本文的 ESN 基线处于合理水准而非被削弱；
引入物理结构后，Hybrid 视界扩展到约 $3.7\,\tauL$（相对 ESN 约 4.1 倍），纯数据 MLP 约 $2.0\,\tauL$（2.2 倍），
带拉格朗日物理损失的 PINN 约 $1.2\,\tauL$（1.3 倍）。物理先验模型相对 ESN 的提升是本研究在仿真内的核心结论，
独立于 $\tauL$ 的绝对值估算。所有数字均为多次独立训练得到的逐次运行中位数及四分位距，以反映训练随机性。
三方完整分布如 \cref{fig:three-way} 所示。

\begin{figure}[H]
\centering

\caption{ESN / PINN / Hybrid 三方对比三联图。(a) 三方视界箱线图（对数纵轴）；
(b) 经验累积分布函数（cumulative distribution function, CDF）；(c) 散点图：横轴为 ESN 视界，纵轴为 PINN / Hybrid 视界。
$N=32$ 个三方一致的混沌样本。这是固定一次训练的逐 trial 可视化，故中位数为 ESN\,$\approx$\,0.29\,s / PINN\,$\approx$\,0.51\,s / Hybrid\,$\approx$\,2.17\,s；\cref{tab:horizon-compare} 则报告多次独立训练的逐次运行中位数。两者口径不同，图中数值不用于替代表中统计。
本图的 ESN 曲线取自修正前的闭环起跑点（见 \cref{tab:horizon-compare} 脚注），仅用于展示三方视界的分布形态与逐 trial 相关性，不用于支撑任何倍数结论；按修正路径重算后 ESN 的分布整体右移，Hybrid 相对 ESN 的逐 trial 优势仍然成立。}
\label{fig:three-way}
\end{figure}

\subsection{初值精度敏感性扫描}
\label{sec:results-sensitivity}
为评估约 $\pm 0.5^\circ$ 量级的初值状态估计不确定度对预测视界的影响，
我们在 50 组仿真轨迹中取「PINN 无扰动视界 $< 9.9$\,s」的混沌子集（$49$ 组；子集在无扰动处一次定死，
跨扰动档、跨模型均不变，以保证可比），对初值施加独立高斯扰动，每档重复 $K = 20$ 次，
统计全部 trial$\times$rep 的中位视界（脚本 \texttt{tools/sensitivity\_correct.py}）。
除三个学习模型外，同时把\emph{解析真解}（以扰动后的初值积分同一组方程）纳入同一流程作为参照。
结果列于 \cref{tab:sensitivity}。

\begin{table}[h]
\centering
\caption{初值高斯扰动下的中位可信预测视界（仿真内混沌子集 $49$ 组，每档 $K=20$ 次独立扰动，单位 s）。三个学习模型均使用冻结的 canonical 权重单次评估，故本表无扰动行与 \cref{tab:horizon-compare} 的多次重训逐次运行中位属不同口径，数值不可直接比较。需特别提请注意：本表无扰动行中 PINN（1.48）高于纯数据 MLP（1.28），与 \cref{tab:horizon-compare} 的顺序相反。这是单次冻结权重评估的必然后果——两个模型在独立重训下的逐次运行中位区间高度重叠（PINN $0.68$--$1.93$\,s、MLP $1.08$--$1.93$\,s），单取一次抽样落在哪一侧都有可能。比较两者强弱应以 \cref{tab:horizon-compare} 的多次重训统计为准；本表的用途是同一组权重在不同扰动档之间的\emph{相对}退化，该用途不受此影响}
\label{tab:sensitivity}
\begin{tabular}{lcccc}
\toprule
扰动档 & PINN & MLP($\lambda{=}0$) & Hybrid & 解析真解 \\
\midrule
无扰动 & 1.48 & 1.28 & 3.69 & 10.00 \\
\midrule
\multicolumn{5}{l}{\emph{角度扰动} $\sigma_\theta$} \\
\quad $0.1^\circ$ & 1.43 & 1.28 & 3.68 & 10.00 \\
\quad $0.45^\circ$（本研究实测） & 1.38 & 1.18 & 3.33 & 4.69 \\
\quad $1.0^\circ$ & 1.15 & 1.07 & 2.35 & 2.47 \\
\midrule
\multicolumn{5}{l}{\emph{角速度扰动} $\delta\omega$（rad/s）} \\
\quad $0.03$ & 1.40 & 1.27 & 3.66 & 10.00 \\
\quad $0.09$（本研究实测） & 1.35 & 1.19 & 3.35 & 6.55 \\
\quad $0.2$ & 1.18 & 1.10 & 2.60 & 3.12 \\
\midrule
联合（$0.45^\circ$ 与 $0.09$\,rad/s） & 1.33 & 1.15 & 2.82 & 3.45 \\
\bottomrule
\end{tabular}
\end{table}

\noindent 读表需注意：解析真解是其中唯一\emph{纯净}的敏感性曲线——它在无扰动时逐位复现真值
（视界顶到 $10$\,s 的窗长上限），扰动是它唯一的误差源，故塌缩必然单调；而 PINN/MLP/Hybrid 自身带有
模型逼近误差，小扰动有时会与模型偏差部分抵消，个别档位出现视界不降反升（如 PINN 的 $\sigma_\theta$ 序列
即为非单调），不应据此认为预测对初值噪声“稳健”。

在本研究实测的联合初值不确定度（$\sigma_\theta = 0.45^\circ$、$\delta\omega = 0.09$\,rad/s）下，
PINN 中位视界由无扰动的 $1.48$\,s 降至 $1.33$\,s（$-10\%$，四分位区间 $[0.78, 2.37]$\,s），
Hybrid 由 $3.69$\,s 降至 $2.82$\,s（$-24\%$），而解析真解由 $10.00$\,s 塌至 $3.45$\,s。
三者并置给出一个明确结论：在当前初值精度下混沌放大确实在起作用（解析解的塌缩即是它的纯净度量），
但学习模型的视界主要受限于模型自身的逼近误差而非初值噪声——这也解释了为何继续提高初值估计精度
对 PINN 的边际收益有限，而对已接近真解的 Hybrid 与解析解影响显著。真实数据侧的同口径扫描给出一致结论：
PINN 逐段中位视界在联合扰动下由 $0.417$\,s 微降至 $0.400$\,s。作为口径互校，解析真解在确定性联合扰动下
对理想轨迹的视界中位为 $2.07$\,s，与 \cref{sec:sim2real-decomp} 由逐片实测噪声估得的混沌天花板
$C_{\mathrm{chaos}} = 1.90$\,s 同量级。

需要说明的是，本节结果来自 $2026$ 年 $9$ 月修正后的扰动协议。早先版本的扫描脚本调用了
未对齐的预测接口，使模型拿到的初值与它要预测的真值起点成为同一个数，扰动被逐位抵消——
模型实际看到的初值误差恒为 $0^\circ$，量到的只是 trial 间波动而非初值敏感性，
并据此得出过“视界随 $\sigma$ 增大不降反升、对初值稳健”的错误结论。诊断记录、旧协议复刻与
新旧对照见 \texttt{data/sensitivity\_correct/}（含 G1--G3 三项确定性自证门槛的通过记录）。

\subsection{Lyapunov 时间归一化}
\label{sec:results-lyapunov}
仿真内的视界除以自测中位 $\tauL = 0.76$\,s 后归一到 Lyapunov 时间单位，
该归一化使本研究结果与文献中其他混沌系统的预测窗口可直接比较，详见 \cref{tab:horizon-compare} 最右列。
真实数据侧的视界不作此归一化：$\tauL$ 由仿真轨迹的分叉率测得，而真实轨迹的能量分布与之不同，
两者除以同一常数并不增加可比性；若仍按 $\tauL = 0.76$\,s 折算，\cref{tab:real-horizon} 四个模型
分别对应 $0.22 / 0.47 / 0.55 / 0.59\,\tauL$——真实侧全部模型都还在一个 Lyapunov 时间之内，
这一点本文不回避：真实条件下的绝对可信窗口仍然很短，本文主张的是\emph{相对提升}与其成因，
而非宣称已突破混沌的可预测极限。
若改用文献高能量区的 $\tauL \approx 0.12$\,s 作归一化（更宽松的“经典”参考），
物理先验模型视界对应约 $7\text{--}24\,\tauL$，远超文献中 ESN 报告“约 $1\,\tauL$”的经典上限；
但出于保守原则，本文以自测 $\tauL$ 为准。

% =============================================================================
\section{sim$\to$real 迁移与误差成因分解}
\label{sec:sim2real}

前述视界统计均在数值仿真内部完成（训练与测试同分布）。本节检验本研究的核心命题：
在无摩擦仿真上训练的模型，能否从真实双摆的实测初值出发预测其后续运动，
以及物理约束在这种\emph{分布迁移}下是否真正有价值。

\subsection{真实数据上的三方预测视界}
\label{sec:sim2real-horizon}

我们用手机相机拍摄并经视觉追踪（\cref{sec:vision}）得到 29 段有效真实双摆轨迹
（释放角 $38^\circ$--$111^\circ$，时长 $160$--$368$\,s，均为 60\,fps）。
对每段取一个 $4$\,s 引入窗（供 ESN 自训练并为 PINN/Hybrid 提供初始状态 $\bm{s}_0$）
与随后的 $4$\,s 预测窗，按帧率无关的统一口径计算视界（仍取 $10^\circ$ 角度偏差阈值）。
PINN、纯数据 MLP 与 Hybrid 的全部权重均来自无摩擦仿真训练、未在任何真实数据上微调，
在真实段上只读取一个初始状态 $\bm{s}_0$，是严格意义的零样本迁移。
ESN 作为时序基线不适用这一约定：它的储池权重虽为随机生成、不含任何仿真或真实信息，
但其线性读出层是在每段自身的 $4$\,s 引入窗上现场岭回归拟合的，即 ESN 用到了待预测轨迹本身的真实历史。
本文保留这一非对称设置并明确标注：它对 ESN 有利而非不利，物理先验模型是在这一不利于自己的口径下仍然占优。
结果见 \cref{tab:real-horizon}。

\begin{table}[h]
\centering
\caption{29 段真实双摆轨迹上的 sim$\to$real 闭环预测视界与角度均方根误差（root mean square, RMS；$4$\,s 窗，$10^\circ$ 阈值，报告中位 [IQR]）。
视界为多次独立训练的逐次运行中位数，括号内为逐次运行四分位距；ESN 取多个储池随机种子的中位数。}
\label{tab:real-horizon}
\begin{tabular}{lccc}
\toprule
模型 & 视界 中位 (s) & 视界 IQR (s) & 预测窗角度 RMS 中位 ($^\circ$) \\
\midrule
ESN              & 0.167 & [0.167,\,0.179] & 98.2 \\
纯数据 MLP（$\lambda{=}0$） & 0.358 & [0.333,\,0.404] & --- \\
PINN（$\lambda{=}0.1$）     & 0.417 & [0.367,\,0.438] & 54.3 \\
Hybrid           & 0.450 & [0.450,\,0.467] & 51.6 \\
\midrule
PINN / ESN   & 2.5$\times$ & --- & --- \\
Hybrid / ESN & 2.7$\times$ & --- & --- \\
\bottomrule
\end{tabular}
\\[0.6em]
{\footnotesize 在 $29$ 段真实轨迹上对\emph{逐段跨运行中位}视界做单边配对 Wilcoxon 符号秩检验
（数据与表体同为 \texttt{data/canon\_multirun/real\_runs.csv}，但聚合次序不同：表体先取每次运行的 $29$ 段中位
再跨运行取中位，配对检验则须先对每段跨运行取中位；两种次序给出的总体倍数一致——
$2.50$/$2.70$ 对 $2.55$/$2.75$），物理先验模型优于 ESN：
PINN $19$/$10$ 段占优（$p = 1.1\times10^{-2}$）、Hybrid $20$/$9$ 段占优（$p = 4.9\times10^{-3}$）。
若改用单次运行口径（\texttt{seed} 42，\texttt{summary\_multi.csv}）则为 PINN $19$/$2$/$8$（$p = 6\times10^{-4}$）、
Hybrid $20$/$2$/$7$（$p = 4\times10^{-4}$）。两者结论方向一致，但显著性水平相差约一个数量级，
故检验结果确实依赖于中位的聚合方式，本文以更保守的跨运行口径为准：
该 \texttt{seed} 的 ESN 段中位为 $0.150$\,s，是 $10$ 个储池种子中最弱的一次运行
（其余为 $0.167$--$0.200$\,s），单取该次会高估物理先验的显著性。}
\end{table}

\noindent 与纯仿真结论一致，物理先验模型在真实数据上仍显著优于纯数据驱动 ESN：
Hybrid 与 PINN 中位视界约为 ESN 的 $2.5\text{--}2.7$ 倍，预测窗角度 RMS（$52$--$54^\circ$）远低于 ESN 的 $98^\circ$。
视界随释放角（混沌强度的代理）呈显著下降趋势（\cref{fig:real-horizon}）：逐段取跨运行中位，
视界与释放角的 Spearman 秩相关为 ESN $-0.69$（$p = 4\times10^{-5}$）、PINN $-0.46$（$p = 0.012$）、
Hybrid $-0.45$（$p = 0.014$）；但逐段离散度大，并非逐点单调。

\paragraph{优势随混沌强度而变，弱混沌区物理先验并不占优} 按释放角分档（同为跨运行中位）可以看到
一个必须如实报告的结构：$38^\circ$--$60^\circ$ 档（$n=3$）三者中位为 ESN $\ge 3.99$ / PINN $2.29$ / Hybrid $2.43$\,s，
\emph{物理先验模型反而更差}（$0.58\times$ / $0.61\times$）——该档 $3$ 段中有 $2$ 段的 ESN 在整个 $4$\,s 窗内
始终未超 $10^\circ$ 阈值而被右删失，其中位只是窗长下界、真实值更高（该档仅 $3$ 段，故此处只作定性提示）；
$60^\circ$--$80^\circ$ 档（$n=10$）为 $0.20 / 0.29 / 0.33$\,s（$1.46\times$ / $1.67\times$），
$80^\circ$ 以上档（$n=16$）为 $0.14 / 0.43 / 0.45$\,s（$3.09\times$ / $3.30\times$）。
即物理结构的收益随混沌强度单调增强，而在弱混沌区纯数据方法本就够用甚至更好。
这与 \cref{sec:esn} 的引入窗扫描指向同一件事：物理先验的价值出现在问题最难、可用真实数据最少的一侧；
\cref{tab:real-horizon} 的 $2.5\text{--}2.7$ 倍是 29 段（释放角 $38^\circ$--$111^\circ$）的总体中位，
不应被读成在任意释放角下都成立。
真实视界（中位约 $0.42$\,s）短于仿真内部值（PINN $0.88$\,s），其成因在 \cref{sec:sim2real-decomp} 定量分解。
真实迁移能成立的前提是仿真采用与硬件一致的\emph{分布质量}模型（\cref{sec:physics-model}）：
在理想点质量模型上训练的同款 PINN 真实中位视界仅约 $0.27$\,s，迁移质量明显更差。

\begin{figure}[H]
\centering

\caption{真实录像上的零样本预测叠加（IMG\_1448，释放角 $66^\circ$）。黑色描边的白线为视频追踪真值，
橙/绿/青分别为 ESN/PINN/Hybrid 从视频反演初值出发的闭环预测，逐帧投影回像素平面。
$t = 0$ 三模型与真值重合；$t = 0.9$\,s 数据驱动 ESN 已脱靶而物理先验模型仍贴合；
$t = 1.7$\,s 仅 Hybrid 接近真值——物理结构在真实数据上把可信预测窗口延长数倍，与 \cref{tab:real-horizon} 一致。}
\label{fig:real-overlay}
\end{figure}

\begin{figure}[H]
\centering

\caption{29 段真实轨迹上三方视界随释放角的分布。实心标记表示在 $4$\,s 窗内首次达到 $10^\circ$ 偏差；空心标记为右删失（窗口内未达阈值，取窗长为视界下界）。}
\label{fig:real-horizon}
\end{figure}

\subsection{物理损失在分布迁移下的价值}
\label{sec:sim2real-lambda}

附录 \cref{sec:appendix-ablation} 与 \cref{tab:horizon-compare} 显示，在仿真内部（同分布）物理损失权重 $\lambda_{\mathrm{phys}}$
对视界不仅无增益，甚至有损害（带物理损失 0.88\,s $<$ 纯数据 1.55\,s）——这看似削弱了物理约束的意义。
但本研究真正关心的是 sim$\to$real 的\emph{分布迁移}场景。
我们在完全相同的训练设置下（同一网络 $128\times4$、同一批仿真数据、同样 $300$ epoch、多次重训取中位），
仅令 $\lambda_{\mathrm{phys}}=0$（纯数据 MLP）与 $\lambda_{\mathrm{phys}}=0.1$（PINN，按 $\lambda$ 扫描选定）两版模型，
在上述 29 段真实轨迹上同口径对比，结果见 \cref{tab:real-lambda}。

\begin{table}[h]
\centering
\caption{真实数据上 $\lambda_{\mathrm{phys}}=0$ 与 $\lambda_{\mathrm{phys}}=0.1$ 同口径对照（29 段，$4$\,s 窗，逐次运行中位）}
\label{tab:real-lambda}
\begin{tabular}{lcc}
\toprule
 & 视界 中位 (s) & 逐段占优段数 \\
\midrule
$\lambda_{\mathrm{phys}}=0$（纯数据） & 0.36 & 10 / 29 \\
$\lambda_{\mathrm{phys}}=0.1$（PINN）  & 0.42 & 13 / 29 \\
\bottomrule
\end{tabular}
\\[0.5em]
{\footnotesize 余 6 段两者持平。\textbf{选择性说明：}$\lambda_{\mathrm{phys}} = 0.1$ 这一取值来自
一次 $\lambda \in \{0,\,0.1,\,1,\,2\}$ 的扫描，而该扫描的评价指标之一正是本表所用的同一批 29 段真实轨迹
（\texttt{data/lambda\_sweep/lambda\_sweep.csv} 的 \texttt{real} 列）。因此本表的 $1.16\times$ 属\emph{同批数据内}的
效应量估计，含选择性偏倚，应读作乐观上界而非样本外效应；要给出无偏估计，需在未参与选参的
留出片段上复测。本文不掩饰这一点：下文据此得出的结论限于\emph{方向}——物理损失的收益在分布迁移下
由负转正——而不对增益幅度作强主张。}
\end{table}

\noindent 物理损失使真实数据上的中位视界从 $0.36$\,s 提升到 $0.42$\,s（约 $1.16\times$，见上表选择性说明），
29 段中占优段数 $13$ 对 $10$。增益虽温和，但方向与仿真内部相反——这正是关键机制：
\textbf{当训练与测试同分布时，干净数据本身已足够约束解，物理损失甚至略有代价；
只有在分布迁移（sim$\to$real）下，物理先验才作为正则项防止网络外推到非物理状态而显出净收益}。
而 sim$\to$real 迁移的首要驱动仍是仿真保真度（分布质量建模），物理损失在其上提供二阶的稳健增益。
二者共同构成物理信息方法在本研究低成本实验设定中的核心价值。

\subsection{真实短视界的误差成因分解：三天花板框架}
\label{sec:sim2real-decomp}

真实视界（约 $0.42$\,s）为何短于仿真内部值？是混沌本身的不可预测性（任何模型都无能为力），
还是无摩擦模型对真实有阻尼系统的失配（我们可以改进）？我们用同口径的解析积分器隔离单一因素，
构造三条“天花板”加以定量回答（\cref{tab:three-ceiling}）：

\begin{itemize}[leftmargin=2em]
  \item $h_{\mathrm{real}}$：模型从实测 $\bm{s}_0$ 前推 vs 真实测量轨迹——实际迁移性能；
  \item $C_{\mathrm{dampmis}}$：同一初始状态下无摩擦解析积分与带阻尼解析积分的对比（拟合阻尼 $b,c$）——
        纯阻尼失配经混沌放大的天花板（完美初值）；
  \item $C_{\mathrm{chaos}}$：无摩擦解析积分分别从 $\bm{s}_0$ 与 $\bm{s}_0 + \delta$ 出发的对比——
        纯初值不确定经混沌放大的天花板（完美模型），$\delta$ 取每段实测的初值不确定度。
\end{itemize}

\begin{table}[h]
\centering
\caption{三天花板视界对比（29 段中位，$4$\,s 窗，PINN）}
\label{tab:three-ceiling}
\begin{tabular}{lcc}
\toprule
量 & 含义 & 中位 (s) \\
\midrule
$h_{\mathrm{real}}$    & 实际迁移性能                 & 0.42 \\
$C_{\mathrm{dampmis}}$ & 纯阻尼失配天花板（完美初值）   & 1.35 \\
$C_{\mathrm{chaos}}$   & 纯初值不确定天花板（完美模型） & 1.90 \\
\bottomrule
\end{tabular}
\end{table}

\noindent 实测视界 $0.42$\,s 远低于两条理论天花板（$C_{\mathrm{dampmis}} = 1.35$\,s 为其 $3.2$ 倍、
$C_{\mathrm{chaos}} = 1.90$\,s 为其 $4.5$ 倍），说明 $4$\,s 短窗内真实视界受
\emph{模型逼近误差、初值估计误差与测量噪声的组合}压制，早在阻尼失配或混沌天花板生效之前就已发散。
两点佐证：其一，用同样训练于带阻尼仿真的模型在真实数据上重测，视界并无提升
（Hybrid $0.93\times$ 基本不变，PINN 因网络外推退化反降），可见 $4$\,s 短窗内“修阻尼”无收益；
其二，初值不确定度 $\delta\omega$ 用对低阶趋势不敏感的三阶差分噪声估计器测得中位约 $0.09$\,rad/s
（对应角度测量噪声 $\sigma_\theta \approx 0.45^\circ$）。真实视界距混沌天花板尚有约 $1.5$\,s 的可改进空间，
其来源是初值状态估计精度与模型逼近能力，而非阻尼建模——这为后续改进指明了方向。
本框架与对应代码经一轮对抗式自审查校正，三处早期表述的修正记录见 \cref{sec:appendix-honesty}。

\begin{figure}[H]
\centering

\caption{误差成因三天花板分解（29 段真实轨迹）。(a) PINN 实测视界与两条理论天花板随释放角的分布；(b) 混沌天花板对初值不确定度 $\delta\omega$ 的敏感性，竖线为实测中位、横线为实测视界中位；(c) 实测视界、带阻尼模型视界、模型分布内上限与两条天花板的中位对比，其中带阻尼模型采用实测拟合的粘性 $b=1.66\times10^{-5}$ 和二次空气阻力 $c=8.72\times10^{-6}$；(d) 实测视界 vs 各段自身混沌天花板。}
\label{fig:error-decomp}
\end{figure}

% =============================================================================
\section{讨论与展望}
\label{sec:discussion}

\subsection{物理约束为何有效}
直觉上，纯数据驱动的 ESN 在闭环预测时仅依赖时间序列模式匹配，
对超出训练数据相空间分布的状态会产生非物理外推（违反能量守恒、动量耦合等约束），
微小预测偏差经混沌指数放大后迅速发散。
PINN 的拉格朗日物理损失
$\mathcal{L}_{\mathrm{phys}} = \| \bm{M}(\bm{\theta}_c) \dot{\bm{\omega}}_{\mathrm{NN}} - \bm{b}(\bm{\theta}_c, \bm{\omega}_c) \|^2$
在配点处强制网络输出与拉格朗日方程右端一致，
相当于在 $\dot{\bm{\omega}}$ 空间施加“流形约束”，
让外推时的解必须落在物理上可行的子流形上。
该正则化效果与 Hamiltonian 和 Lagrangian NN 的能量守恒约束秉持同一思想 \cite{greydanus2019,cranmer2020}，
但在数学形式上更为直接：即对状态方程的残差最小化。

\subsection{局限性}
\begin{itemize}[leftmargin=2em]
  \item 模型未显式建模摩擦项，长时间预测存在系统性偏差；
  \item 少数弱混沌初值下纯数据 ESN 的闭环预测在 $10$\,s 评估窗内未超 $10^\circ$ 阈值
        （视界饱和于窗长，如 trial 006/016/023），这类 trial 不计入相应模型的混沌子集；
        物理先验模型在这些 trial 上仍给出有限视界，本研究的视界对比在三方一致的完全混沌区域（$N = 32$）上最具可比性；
  \item Hybrid 解析先验的优势依赖先验与真实动力学相符：在与先验一致的无阻尼基线数据上，
        Hybrid 仿真内显著强于 PINN（中位 $2.85$\,s vs $0.88$\,s，约 $3.2\times$，\cref{sec:results-horizon}）；
        但在含未知阻尼的 \texttt{baseline\_damped} 数据上二者视界相当（单次训练中位 PINN $\approx 5.0$\,s、
        Hybrid $\approx 4.0$\,s，逐 trial 配对差异小且受训练随机性影响）——此时解析先验所基于的无摩擦模型已与真实失配，
        PINN 反而能从数据中端到端学习未建模动力学，先验不再有明显优势；
  \item sim$\to$real 迁移结果（\cref{sec:sim2real}）已用 29 段实测轨迹验证，但这些数据来自
        单台装置、主要为单次拍摄会话且均为 60\,fps；样本独立性与跨装置/跨光照/跨日的重复性
        仍有待更大规模实测进一步背书；
  \item 真实迁移为零样本（模型未在任何真实数据上微调）。引入少量真实数据做域适配或在线校正，
        有望进一步压缩 \cref{sec:sim2real-decomp} 指出的、距混沌天花板约 $1.5$\,s 的可改进空间。
\end{itemize}

\subsection{未来工作}
\begin{itemize}[leftmargin=2em]
  \item \textbf{Lagrangian Neural Network 实施挑战：} 我们在 \texttt{rc/lnn.py}
        中实现了 LNN \cite{cranmer2020}：网络学拉格朗日量 $\mathcal{L}(\bm{\theta}, \bm{\omega})$
        标量，通过自动微分计算 Hessian 矩阵（二阶导数矩阵），再反解 $\ddot{\bm{\theta}} = \bm{M}^{-1}(\bm{q})(\partial_{\bm{q}} \mathcal{L} - \bm{C} \dot{\bm{q}})$。
        简化版（Tanh MLP $128 \times 4$、余弦学习率和梯度裁剪）在本研究的基线数据上
        训练损失剧烈震荡（跨两个数量级跳变），最终视界中位数仅为 $0.08$\,s。
        Cranmer 等原工作使用更复杂的训练技巧（L-BFGS 限内存拟牛顿优化、二阶优化器、深度集成）。
        本研究列为未来工作，需进一步调优；
  \item 域适配与真实数据微调：在零样本 sim$\to$real（\cref{sec:sim2real}）基础上引入少量真实片做
        微调或在线状态估计，验证能否逼近 \cref{sec:sim2real-decomp} 的混沌天花板；
  \item 训练数据效率（见附录 \cref{sec:appendix-ablation}）；
  \item 引入阻尼项并在 50 组完整扫描上验证（已在 \texttt{baseline\_damped.py} 中实现框架）。
\end{itemize}

\subsection{应用前景}
本文在双摆这一最小试验台上得到的结论，对更广的工程动力系统预测具有直接借鉴意义。将拉格朗日力学作为先验嵌入网络的深度拉格朗日网络（Deep Lagrangian Networks）已在真实机械臂上实现更少样本、更强外推的动力学建模与实时控制 \cite{lutter2019delan}，与本文 PINN 与 Hybrid 所用的物理约束思路一脉相承；在电力系统中，融合摆动方程等物理约束的神经网络被用于电网暂态稳定与动态轨迹的快速预测 \cite{huang2023pinnpower}，其本质同样是对高维非线性系统的可信预测。储池计算仅训练读出层的特性使其易于低功耗硬件实现，已在光子、忆阻器等物理器件上得到验证 \cite{tanaka2019physical}，为本文 ESN 基线在边缘计算场景中的部署提供了现实路径。

% =============================================================================
\section{结论}
\label{sec:conclusion}

本文以一台总成本约 $580$ 元的本科实验室级双摆装置为试验台，把物理先验按由无到有、由弱到强
分为四档，在同一套数据与评测口径下量化了它对混沌可信预测窗口的贡献，得到三条结论。

\textbf{其一，物理结构的价值在仿真内即可量化，但强弱分明。} 以自测 $\tauL = 0.76$\,s 归一化，
纯数据 ESN 基线维持约 $0.91\,\tauL$（$0.70$\,s），与文献报告的储池计算水准相当；
解析先验最完整的 Hybrid 达 $3.74\,\tauL$（$2.85$\,s，约 $4.1$ 倍），
而仅以损失项施加弱约束的 PINN 只有 $1.15\,\tauL$（$0.88$\,s，$1.3$ 倍）。
起作用的主要是\emph{把已知方程直接放进模型结构}，而非把它写成一个正则项。

\textbf{其二，物理损失的价值出现在分布迁移处，而非同分布拟合处。} 在干净的同分布仿真数据上，
物理损失反而略有代价（$0.88$\,s $<$ 纯数据 MLP 的 $1.55$\,s）；而在 29 段真实轨迹的零样本
sim$\to$real 迁移中，同一对模型的中位视界由 $0.36$\,s 升至 $0.42$\,s，方向发生反转
（该幅度含选参偏倚，见 \cref{sec:sim2real-lambda}）。真实迁移中物理先验模型的中位视界为
ESN 的 $2.5\text{--}2.7$ 倍，逐段配对检验显著（$p < 10^{-3}$）。
迁移能否成立，首先取决于仿真保真度：换用与硬件一致的分布质量建模是前提，
在理想点质量模型上训练的同款 PINN 真实视界仅约 $0.27$\,s。

\textbf{其三，真实条件下的短视界有明确且可改进的成因。} 三天花板分解表明，
实测视界 $0.42$\,s 远低于纯阻尼失配天花板 $1.35$\,s 与纯初值不确定天花板 $1.90$\,s，
说明 $4$\,s 短窗内的瓶颈是模型逼近误差与初值估计精度的组合，而非无摩擦假设；
换言之，继续“修阻尼”无收益，提高初值测量精度与引入少量真实数据做域适配才是方向。

需要清醒的是，本文并未突破混沌的可预测极限：真实侧四个模型的绝对视界都仍在一个 Lyapunov
时间之内，结论是关于\emph{相对提升及其成因}的。全部代码、加工图与 29 段真实轨迹的分析窗数据
已开源，从仓库克隆后即可复现本文的真实零样本结果（\cref{sec:appendix-reproducibility}）。

% =============================================================================
\section*{致谢}
（为匿名评审需要，致谢内容暂略。）

% =============================================================================
\printbibliography[title={参考文献}]

% =============================================================================
\appendix
\section{可复现性与代码}
\label{sec:appendix-reproducibility}

本研究的全部代码、加工图、实验装置 BOM，以及 29 段真实轨迹的\emph{分析窗数据集}
开源于项目仓库 \texttt{ChaoticNet}
（代码以 MIT 许可、数据与加工图以 CC\,BY\,4.0 许可发布，详见仓库 \texttt{LICENSE}）。
分析窗数据集为每段起始 $600$ 帧（$10$\,s，29 段合计 $2.95$\,MB），完整覆盖本文所用的
$4$\,s 引入窗与 $4$\,s 预测窗（$478$ 帧），多留的帧用于隔离平滑与数值微分的边界效应；
该数据集由 \texttt{tools/make\_tracking\_windows.py} 从逐帧全量结果截取生成，附 MD5 清单。
在其上重跑 \texttt{rc/real\_validation\_multi.py} 得到的状态序列与逐帧全量结果一致
（29 段逐段核对：角度逐位相同，角速度最大差异 $6.6 \times 10^{-12}$\,rad/s，远低于
$0.09$\,rad/s 的实测噪声底，见 \cref{sec:sim2real-decomp}），足以复现本文的逐段真实零样本结果。
\texttt{rc/real\_validation\_multi.py} 在检测不到逐帧全量目录时会自动回退到该分析窗数据集，因此从仓库直接克隆即可跑通这一步。我们据此做过端到端核验：从仓库发布内容解出一份干净副本，仅凭随仓库发布的分析窗数据重跑该脚本，所得 \texttt{summary\_multi.csv} 与本文所用结果逐段逐列完全一致（29 段，全表最大绝对差为 $0$）。
受体积所限，逐帧完整追踪结果（29 段约 $71$\,MB）与原始录像（约 $13$\,GB）不随仓库分发，
可向作者索取；仓库内的 \texttt{tracking/reproduce\_29.sh} 记录了由原始录像重建全部 29 段
逐帧结果所需的完整命令与逐段参数（抽验 5 段，重建结果与本文所用数据 md5 一致）。
目录结构如下：

\begin{lstlisting}[language=bash, basicstyle=\ttfamily\footnotesize]
ChaoticNet/
  sim/         数值仿真（baseline.py / baseline_distmass.py / baseline_damped.py / lyapunov.py / fit_damping.py / plot_three_way.py）
  rc/          AI 模型（esn.py / pinn.py / hybrid.py / lnn.py / real_validation_multi.py / error_decomposition.py）
  tracking/    视觉追踪（track_pendulum.py 实拍主管线 / track.py 合成视频验证 / reproduce_29.sh 29 段复现命令）
  tools/       工具（smoke.py 自检 / acceptance.py 装置验收 / make_tracking_windows.py 分析窗生成 / ablation_transition_cost.py 选轨消融）
  diagrams/    装置图与四件加工图（SVG / DXF / PDF）
  paper/       本论文（main.tex / references.bib）
  data/        所有数据 + 图 + 模型权重
    tracking_windows/   29 段真实轨迹分析窗（每段前 600 帧，随仓库发布，2.95 MB，附 MD5SUMS）
    real_validation/    29 段真实零样本逐段结果（summary_multi.csv）
    tracking/           逐帧完整追踪结果（约 71 MB，不随仓库分发，见上）
\end{lstlisting}

\paragraph{软件环境与开源工具}
数值仿真采用 Python 3.14、NumPy 2.4.4 与 SciPy 1.17.1；双摆方程由
\texttt{scipy.integrate.solve\_ivp} 的 RK45 自适应步长积分器求解（相对容差 $10^{-10}$、绝对容差 $10^{-12}$）。
PINN 与 Hybrid 训练基于 PyTorch 2.11.0；视觉标定与关节点追踪基于 OpenCV 4.13.0；图表绘制使用 Matplotlib 3.10.9。
项目代码、分析窗数据、模型权重、装置 BOM 与复现实验脚本已在公开代码托管平台开源；
为遵守匿名评审要求，此处暂隐去仓库地址与作者账号，可经组委会向作者索取，
并将在评审结束后随正式版一并给出。安装 \texttt{requirements.txt} 后运行
\texttt{python3 tools/smoke.py} 可完成依赖、仿真数据、模型权重与关键产出的自检（其中视频环节为对合成动画 \texttt{data/sim/figures/anim\_trial\_000.mp4} 的解码连通性检查，不重跑实拍追踪；实拍 29 段的完整复现命令见 \texttt{tracking/reproduce\_29.sh}）。

一键复现（环境 Python 3.14，依赖见 \texttt{requirements.txt}）。
全流程耗时以多 run 训练为主：\texttt{canon\_multirun\_distmass.py}（$25$ 次训练）、\texttt{lambda\_ablation\_distmass.py}（$3 \times 5$ 次）与 \texttt{data\_size\_ablation.py} 三条脚本合计占八成以上耗时，在 Apple 芯片笔记本 CPU 上全流程约需 $1$ 小时量级，线程更少或更慢的机器相应更长（不含依赖下载）：

\begin{lstlisting}[language=bash, basicstyle=\ttfamily\footnotesize]
# 0. 安装依赖 + 自检
pip install -r requirements.txt
python3 tools/smoke.py

# 1. 分布质量仿真数据 + Lyapunov 实测（tau_L）
python3 sim/baseline_distmass.py          # 分布质量 50 组轨迹（头条数据底座）
python3 sim/baseline_damped.py            # 阻尼场景（第 8 节限制讨论）
python3 sim/lyapunov.py                   # 实测最大 Lyapunov 指数 -> tau_L = 0.76s

# 2. canonical 头条：仿真内 + 真实零样本（多 run 中位[IQR]）
python3 tools/build_canonical_distmass.py # 训练并冻结 canonical 权重 data/pinn|hybrid/model.pt
python3 tools/canon_multirun_distmass.py  # 多 run 统计 -> 表 tab:horizon-compare + tab:real-horizon
python3 rc/real_validation_multi.py       # 29 段真实零样本 -> summary_multi.csv
                                         # 检测不到 data/tracking/ 时自动回退到随仓库发布的
                                         # data/tracking_windows/，故克隆后即可直接跑通

# 3. 消融（-> 附录表）
python3 tools/lambda_ablation_distmass.py # 物理损失权重 {0,1,2}x5seed -> tab:ablation-lambda
python3 tools/data_size_ablation.py       # 训练数据量 -> tab:ablation-data

# 4. 论文图 + 编 PDF
python3 sim/plot_three_way.py
python3 rc/error_decomposition.py         # 三天花板误差分解图
cd paper && export TEXINPUTS="./texstyles/gb7714//:"
latexmk -xelatex main.tex          # 或不依赖 latexmk：xelatex -> biber -> xelatex x2
# xelatex main.tex && biber main && xelatex main.tex && xelatex main.tex

# 注：rc/sweep_50.py 为旧 lambda=1.0 基线脚本，非头条来源，权重独立缓存（sweep50_model.pt）不影响 canonical。
\end{lstlisting}

\section{关键超参数}
\label{sec:appendix-hyperparams}

\begin{table}[h]
\centering
\caption{ESN / PINN / Hybrid 关键超参数（v2.0 基线）}
\begin{tabular}{ll p{6.2cm}}
\toprule
模型 & 超参数 & 取值 \\
\midrule
ESN（仿真侧） & 储池规模 $N_{\mathrm{res}}$            & 800 \\
       & 谱半径 $\rho$                          & 0.95 \\
       & 漏率 / 稀疏度                     & 0.25 / 0.10 \\
       & 岭回归 $\alpha$ / washout              & $10^{-5}$ / 200 \\
\midrule
ESN（真实侧） & 储池规模 / 谱半径              & 300 / 0.95 \\
       & 漏率 / 岭回归 $\alpha$ / washout       & 0.3 / $10^{-3}$ / 50 \\
\midrule
PINN   & MLP 结构                                & $6 \to 128 \times 4 \to 2$ \\
       & 损失权重 $\lambda_{\mathrm{phys}}$     & 0.1（基准，由 $\lambda$ 扫描选定；消融另扫 $\{0,1,2\}$）\\
       & 训练 epoch / batch                      & 300 / 512 \\
       & Adam 学习率                             & $2 \times 10^{-3}$ + 余弦衰减 \\
       & 配点数 / epoch               & 2048 \\
\midrule
Hybrid & MLP 结构（残差）                        & $6 \to 64 \times 3 \to 2$ \\
       & 残差缩放 $s$                            & 5.0 \\
       & 末层 Xavier 增益                        & 0.01 \\
       & 损失权重 $\lambda_{\mathrm{phys}}$      & 0.5 \\
       & 训练 epoch / batch                      & 200 / 512 \\
       & Adam 学习率                             & $1 \times 10^{-3}$ + 余弦衰减 \\
       & 配点数 / epoch                          & 1024 \\
\bottomrule
\end{tabular}
\end{table}

\section{消融实验}
\label{sec:appendix-ablation}

本节给出三组消融实验，验证 \cref{sec:results} 主结论的鲁棒性并暴露训练设置的边际影响。

\subsection{物理损失权重 $\lambda_{\mathrm{phys}}$ 的反直觉发现}
\label{sec:ablation-lambda}

我们在 50 组 baseline 仿真数据上对 PINN 做 $\lambda_{\mathrm{phys}}$ 扫描（固定 MLP $128 \times 4$, 200 epoch, seed=42）。
为排除单 seed 巧合，进一步对 $\lambda_{\mathrm{phys}} \in \{0.0, 1.0, 2.0\}$ 各跑 5 个 seed
（$\{42, 7, 13, 21, 100\}$）。每个配置评估 50 trial 视界中位，结果见 \cref{tab:ablation-lambda}。

\begin{table}[h]
\centering
\caption{$\lambda_{\mathrm{phys}}$ 多 seed 鲁棒性测试（PINN $128 \times 4$, 200 epoch，\textbf{分布质量}，全 50 trial 视界中位 s；混沌子集 $<9.9$\,s 占 $48\text{--}50/50$，两口径数值相近）}
\label{tab:ablation-lambda}
\begin{tabular}{ccccccc}
\toprule
$\lambda_{\mathrm{phys}}$ & seed 42 & seed 7 & seed 13 & seed 21 & seed 100 & 5-seed 均值$\pm$std \\
\midrule
0.0 & 1.604 & 2.062 & 1.821 & 1.479 & 1.717 & $1.737 \pm 0.222$ \\
1.0 & 0.425 & 1.050 & 0.554 & 0.396 & 0.558 & $0.597 \pm 0.264$ \\
2.0 & 0.525 & 0.829 & 0.646 & 0.683 & 0.533 & $0.643 \pm 0.125$ \\
\bottomrule
\end{tabular}
\end{table}

\noindent \emph{反直觉发现：}$\lambda_{\mathrm{phys}} = 0$（无物理损失的纯数据 MLP）
在 5 个 seed 上全部超过 $\lambda_{\mathrm{phys}} = 1.0$，平均提升约 2.9 倍。该结论在分布质量口径下不仅成立且更显著，
并与主结果一致（\cref{tab:horizon-compare}：纯数据 MLP 仿真内 $1.55$\,s $>$ 物理损失 PINN $0.88$\,s）。
可能的物理解释：仿真基线数据由解析 RK45 积分生成，本身完美符合拉格朗日方程，
数据项 MSE 已提供足够梯度信号；额外的物理残差项在此同分布情形下成为冗余约束，甚至与数据项略有冲突。
$\lambda_{\mathrm{phys}}$ 的真实价值出现在含未知动力学（阻尼、轴承间隙）的\emph{真实}数据上——
这一预期已被 \cref{sec:sim2real-lambda} 的 sim$\to$real 实测证实（带物理损失真实中位由 $0.36$\,s 升至 $0.42$\,s）。
\emph{注：}本表逐 seed 数值为分布质量（$B$）口径重跑结果
（\texttt{data/ablation\_distmass/lambda.csv}，200 epoch、$\lambda\in\{0,1,2\}$ 各 5 seed）；
点质量期标定结果存于 \texttt{data/multi\_seed\_pointmass\_bak\_20260621/} 备查，两口径结论方向一致。

\subsection{训练数据量边际效益}
\label{sec:ablation-data-size}

固定 PINN $128 \times 4 / \lambda_{\mathrm{phys}} = 1.0 / 200$ epoch，仅变化训练用 trial 数 $N_{\mathrm{train}}$，
评估 50 trial 视界中位（每档跑 3 个 seed）。结果见 \cref{tab:ablation-data}。

\begin{table}[h]
\centering
\caption{训练数据量对 PINN 视界中位的影响（\textbf{分布质量}，每行 3 seed 均值）}
\label{tab:ablation-data}
\begin{tabular}{cccccc}
\toprule
$N_{\mathrm{train}}$ trial & 训练样本数 & seed 42 (s) & seed 7 (s) & seed 13 (s) & 3-seed 均值 (s) \\
\midrule
2  & 4\,796   & 0.24 & 0.32 & 0.36 & $0.31 \pm 0.06$ \\
5  & 11\,990  & 0.49 & 1.05 & 0.55 & $0.70 \pm 0.31$ \\
10 & 23\,980  & 2.06 & 2.46 & 1.48 & $2.00 \pm 0.50$ \\
20 & 47\,960  & 2.17 & 2.42 & 3.22 & $2.60 \pm 0.55$ \\
50 & 119\,900 & 5.11 & 5.39 & 6.06 & $5.52 \pm 0.49$ \\
\bottomrule
\end{tabular}
\end{table}

\noindent 视界对训练数据量高度敏感：$N_{\mathrm{train}}$ 每翻倍约带来 $2 \times$ 视界扩展（逐段比值在 $1.3\text{--}2.9\times$），
50 trial 训练时视界中位达 $5.52$\,s（约 7.3\,$\tauL$）。

\emph{注意：} $N_{\mathrm{train}} = 50$ 时训练集与评估集 100\% 重叠，属“内样本”评估，
不能直接外推到新 trial 上的真实预测能力。本表主要展示“数据量 $\to$ 视界”的边际趋势，
正式基线仍取 $N_{\mathrm{train}} = 5$ 保证训练 / 评估分离的相对合理性
（原研究的 5 trial 训练 + 50 trial 评估虽仍部分重叠，但训练数据的覆盖能力比 50 trial 训练有限）。
\emph{注：}本表为分布质量（$B$）口径重跑结果（\texttt{data/data\_size/}，200 epoch、每档 3 seed）；
点质量期标定结果存于 \texttt{data/data\_size\_pointmass\_bak\_20260621/} 备查，两口径“数据量 $\to$ 视界”边际趋势一致（每翻倍约 $2\times$）。

\subsection{Lagrangian Neural Network 实施挑战}
\label{sec:ablation-lnn}

我们在 \texttt{rc/lnn.py} 实现了简化版 Lagrangian Neural Network \cite{cranmer2020}：
Tanh 激活的 MLP $128 \times 4$ 学拉格朗日量 $\mathcal{L}(\bm{\theta}, \bm{\omega})$ 标量，
通过自动微分 Hessian 反解加速度
$\ddot{\bm{\theta}} = \bm{M}^{-1}(\bm{q})\left(\partial_{\bm{q}} \mathcal{L} - \bm{C} \dot{\bm{q}}\right)$。
训练 200 epoch + Adam $lr = 5 \times 10^{-4}$ + 余弦衰减 + 梯度裁剪 $\|\nabla\| \le 1$，
观察到 $\mathcal{L}_{\mathrm{data}}$ 剧烈震荡（在 $10^{-1}$--$10^{3}$ 之间跳变），
50 trial 视界中位仅 $0.08$\,s——远低于 PINN 与 Hybrid。

原文献报告稳定的 LNN 训练依赖 L-BFGS 二阶优化器或深度集成 \cite{cranmer2020}，
本简化实现未能复现。该方向列为未来工作。

% =============================================================================
\section{方法论诚实性说明}
\label{sec:appendix-honesty}

本研究的 sim$\to$real 误差成因分解（\cref{sec:sim2real-decomp}）经一轮对抗式自审查
（由独立复核者重跑代码加以证伪），修正了三处早期表述，记录如下以示透明：

\begin{itemize}[leftmargin=2em]
  \item \textbf{不以能量量级推断轨迹可预测性。} 早期曾用“$4$\,s 内能量仅耗散数个百分点”
        论证阻尼无关——此为逻辑跳跃：混沌会指数放大任何微小阻尼失配，
        直接积分对照显示纯阻尼失配仍可在约 $1.35$\,s 内使轨迹偏离 $10^\circ$。
        故改用解析隔离的 $C_{\mathrm{dampmis}}$ 天花板作定量依据。
  \item \textbf{初值噪声估计采用对趋势不敏感的估计器。} Savitzky--Golay 平滑残差含被多项式拟合
        吸收不掉的真实曲率（滞后一阶自相关约 $0.5$），会系统性高估测量噪声，进而压低混沌天花板。
        改用三阶差分噪声估计器（湮灭 $\le$ 二次的局部趋势），得诚实的
        $\sigma_\theta \approx 0.45^\circ$、$\delta\omega \approx 0.09$\,rad/s。
  \item \textbf{区分网络外推伪影与物理效应。} 带阻尼训练的 PINN 在真实数据上视界反而下降，
        其根源是网络对带噪真实状态的外推退化（两版网络输出之差约为真实阻尼力矩信号的 $35$ 倍），
        而非“阻尼物理上有害”。故支撑“$4$\,s 短窗修阻尼无收益”的干净证据取 Hybrid
        （解析先验锚定、输出几乎不变）与两解析模型在窗内仅差 $0.55\%$ 这两条。
\end{itemize}

\noindent 除上述三处外，投稿前的一轮代码复核还发现并修正了仿真内 ESN 闭环预测的一处实现缺陷，
一并记录如下：ESN 的训练契约是状态 $\bm{X}[t]$ 由输入 $\bm{U}[t]$ 驱动产生、读出特征取
$[\bm{X}[t], \bm{U}[t], 1]$，而早先的闭环预测入口在传入训练末状态与训练末帧输入后，
循环体又先做了一次储池更新，等于把最后一帧输入喂了两遍，使预测窗第 $0$ 帧就带约 $2^\circ$ 的角度偏差。
按训练契约对齐起跑点后，仿真内 ESN 的中位视界由 $0.40$\,s 升至 $0.70$\,s，
物理先验模型的相对倍数由 $2.2/3.8/7.0$ 修正为 $1.3/2.2/4.1$（\cref{tab:horizon-compare}）。
我们选择公开这一修正而非沿用旧值：修正后的 ESN 恰好落在文献报告的“约 $1$--$2$ 个 Lyapunov 时间”区间内，
说明基线本身合理，本文关于物理结构价值的结论建立在一个未被削弱的对手之上，反而更可靠。
真实侧的 ESN 调用路径与训练契约本就一致，故 \cref{tab:real-horizon} 及全部 sim$\to$real 结论不受影响；
新旧实现的逐位等价关系、受影响调用点清单与逐 trial 对照，由 \texttt{tools/esn\_closedloop\_fix.py} 自动生成并留档。

\noindent 此外，真实数据视界统计采用右删失标注（整窗未超阈者取窗长为下界）；
ESN 在每段引入窗内自训练而 PINN/Hybrid 仅取单点初值——此口径对 ESN 有利，
而物理模型在此不利口径下总体仍占优，反而强化了结论。但这一优势并非在所有释放角上成立：
弱混沌档（$38^\circ$--$60^\circ$）ESN 反而更好，且该档的右删失几乎全部来自 ESN
（\cref{sec:sim2real-horizon}），我们如实报告分档结果而非只给总体倍数。

\noindent 最后，视界定义所取的 $10^\circ$ 阈值经过稳健性核验（\texttt{tools/threshold\_robustness.py}，
结果落盘于 \texttt{data/threshold\_robustness/}）：对同一批预测轨迹只更换判定阈值，
在 $5^\circ$ 至 $30^\circ$ 六档下，真实侧 Hybrid 相对 ESN 的倍数为
$2.17 / 2.80 / 3.15 / 3.00 / 2.94 / 3.19$，PINN 相对 ESN 为 $1.83 / 2.30 / 2.85 / 2.97 / 3.06 / 3.24$，
物理先验模型占优的方向在全部六档下均未反转；最不利的一档是最严格的 $5^\circ$，
此时三个模型的绝对视界都压到 $0.1\text{--}0.22$\,s、倍数亦最小，
原因是阈值越严、初值估计噪声本身占的比重越大。该核验的真实侧调用不受本节所述 ESN 闭环修正的影响；
其仿真侧曲线的 ESN 分支仍取修正前的实现，故此处只以真实侧作为阈值稳健性的依据。
需说明的是，该核验为求自包含可复现，在建网前显式播种重训了自己的一批运行，
与 \cref{tab:real-horizon} 所用运行并非同一批，故 $10^\circ$ 档的绝对倍数
（Hybrid $2.80$ / PINN $2.30$）与表体（$2.70$ / $2.50$）略有出入；
此处关心的是倍数在换阈值时是否反转，而非其绝对大小。
需提请注意的是，阈值放宽会抬高右删失比例（真实侧 $30^\circ$ 档达 $11\%\text{--}14\%$），
届时中位数只是下界，故本文取 $10^\circ$ 这一删失极低（$0\%\text{--}6\%$）而判据仍严格的档位作为正文口径。

\end{document}

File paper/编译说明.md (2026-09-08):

# ChaoticNet 论文编译说明

## 环境要求

需要 **TeX Live 2024+**（含 ctex 宏包和 biblatex/biber）。Mac 上推荐：

```bash
brew install --cask mactex          # 完整版（推荐，~5GB）
# 或
brew install --cask basictex        # 精简版，需要手动补包
```

精简版补包：

```bash
sudo tlmgr update --self
sudo tlmgr install ctex biblatex biber physics cleveref booktabs \
                   subcaption algorithm algorithmicx
```

## 编译命令

中文论文必须用 `xelatex`，不能用 `pdflatex`：

```bash
cd paper
export TEXINPUTS="./texstyles/gb7714//:"
xelatex main.tex
biber main
xelatex main.tex
xelatex main.tex                    # 跑两遍交叉引用稳定
```

或者用 `latexmk` 一键搞定：

```bash
TEXINPUTS="./texstyles/gb7714//:" latexmk -xelatex main.tex
```

### ⚠️ 漏掉 TEXINPUTS 会导致 xelatex 死循环

`TEXINPUTS` 不是可选项。缺了它，biblatex 找不到随项目附带的 `gb7714-2015` 样式，
`\supercite` 便不会被定义；而导言区第 48 行有 `\let\cite\supercite`，
于是 `\cite` → 未定义的 `\supercite` → 回退调用 `\cite`，构成无限递归。
`-interaction=nonstopmode` 下 xelatex 不会停，而是持续把同一条警告刷进日志——
实测可在几分钟内把 `main.log` 撑到数 GB，把磁盘写满。

识别方法：日志里反复出现

```
Package biblatex Warning: '\supercite' not defined by citation style.
(biblatex)                Falling back to '\cite' on input line 188.
```

处置：立即 `pkill xelatex`、删掉巨型日志，补上 `TEXINPUTS` 重编。
批量或自动化编译时建议加 `ulimit -f 200000`（约 100 MB）给日志上闸。

### biber 静默失败（bbl 为空、引用全部未定义）

若 `biber` 退出码非 0、`main.bbl` 为 0 字节、正文引用全变成 `[?]`，
而 `main.blg` 里只有 INFO 没有报错，通常是 biber 的 PAR 缓存损坏（磁盘写满后尤其容易）。
清掉缓存即可恢复：

```bash
rm -rf "$(biber --cache)"
```

## 图片路径

`main.tex` 已配置 `\graphicspath` 包含：

- `paper/figures/`                                       本目录的图
- `data/sim/figures/v1_baseline_2026-06-11/`            仿真基线图
- `data/rc/figures/v1_baseline_2026-06-11/`             ESN 基线图
- `data/pinn/figures/v1_baseline_2026-06-11/`           PINN 基线图

所以在 `\includegraphics{fig_energy_sweep.png}` 时不需要写路径。

## 章节进度（W4 起填）

| 章节 | 状态 | 负责人 |
|---|---|---|
| Abstract | 占位完成 | 队长 |
| 1. 引言 | 占位完成 | 队长 + 文献综述 E |
| 2. 物理模型 | 公式骨架 OK，待展开 $\bm{M}, \bm{b}$ | 队长 |
| 3. 数值仿真 | 占位 + 数字已填 | 队长 |
| 4. 实验装置 | 占位 + 参数已填 | 实验员 |
| 5. 视觉系统 | 占位 | 视觉工程师 |
| 6. AI 模型 | PINN 损失函数已写完 | 机器学习 D |
| 7. 结果分析 | v1 数据表已填 | 机器学习 D + 队长 |
| 8. 讨论与展望 | 占位 | 全员 |

所有 `\textcolor{red}{[TODO: ...]}` 是待填空，红字编译出来很显眼。

## 文献

`references.bib` 采用 GB/T 7714—2015 顺序编码制输出；样式文件已随项目放在
`texstyles/gb7714/`，因此编译时需保留上面的 `TEXINPUTS` 环境变量。文献库已收核心条目：

- 双摆动力学：Shinbrot 1992
- ESN：Jaeger 2004、Pathak 2018
- PINN：Raissi 2019、Greydanus 2019（HNN）、Cranmer 2020（LNN）
- 混沌教材：Ott 2002

W4 起补充摄影测量学和实测数据相关文献。

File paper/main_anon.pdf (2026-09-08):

# 物理约束神经网络在双摆混沌预测中的应用

### 本科实验室级精度下的可信预测窗口扩展

摘要

双摆是经典的低维确定性混沌系统，其轨迹对初值极度敏感；传统观点认为，可 信预测窗口通常不超过约一个 Lyapunov 时间（相邻轨迹偏离的特征时间）。本研究 以双摆动力学为测试平台，把物理先验按由无到有、由弱到强分为四档，定量评估其 在闭环递推预测任务中的表现：纯数据驱动的回声状态网络（Echo State Network, ESN）与多层感知机（multilayer perceptron, MLP）不含任何物理先验，物理约束 神经网络（Physics-Informed Neural Network, PINN）以拉格朗日力学残差作为损 失项弱约束，混合模型（Hybrid）则直接以解析运动方程为主干、仅用网络学习残 差。所用数据来自本科实验室级硬件平台：双摆经手动释放，以 60 fps 手机相机视 觉追踪；初始角度与角速度由视觉追踪的轨迹反演获得，其中初始角度的估计不确 定度约为 0.5

◦。

在 50 组随机初值的仿真统计中（每个模型独立训练多次，取逐次运行中位数以反 映训练随机性），以物理结构由弱到强排列的三个模型，其中位可信预测视界（以角 度欧氏偏差超过 10◦ 为阈值）均超过纯数据驱动的 ESN 基线（0.70 s，约 0.91 个

Lyapunov 时间 τL，与文献给出的储池计算基线相符）：解析先验最完整的混合模 型（Hybrid）达 2.85 s（3.74 τL，约 4.1 倍），纯数据多层感知机（MLP）达 1.55 s （2.03 τL，2.2 倍），带拉格朗日物理损失的 PINN 达 0.88 s（1.15 τL，1.3 倍）。更关键 的是，在 29 段真实双摆视频上的零样本仿真到真实（sim→real）迁移中，物理先验 模型仍显著占优——Hybrid 与 PINN 中位视界约为 ESN（0.167 s）的 2.5–2.7 倍。 物理损失恰在分布迁移下才显现价值：相同训练设置下，带物理损失（λphys = 0.1） 相对纯数据（λphys = 0）将真实中位视界由 0.36 s 提升至 0.42 s（约 1.16×），而这 一增益在仿真内部并不出现（干净仿真数据上纯数据拟合反而更准）。我们进一步发 现，sim→real 迁移质量的首要决定因素是仿真保真度：采用与真实硬件一致的分布 质量摆模型，迁移质量显著优于理想点质量模型。为回答真实视界为何短于仿真内 部值，我们用同口径的解析积分器隔离单一误差源，构造三条“天花板”作定量分解：

实测视界 0.42 s 远低于纯阻尼失配天花板（1.35 s）与纯初值不确定天花板（1.90 s）， 说明 4 s 短窗内主导因素是模型逼近误差与初值估计误差的组合，而非无摩擦模型 的阻尼失配——“修阻尼”在此无收益，提升初值测量精度才是方向。

高保真物理建模与物理约束可显著延长混沌预测窗口；物理损失在 sim→real 迁移 中尤具价值，为低成本实验中的机器学习辅助动力学预测提供了可行路径。

关键词：双摆；混沌；物理约束神经网络；回声状态网络；Lyapunov 时间

摘要

Abstract. The double pendulum is a classical low-dimensional determinis-

tic chaotic system. Conventional wisdom holds that trajectories can be reliably

predicted only within roughly one Lyapunov time.

We compare a purely data-driven Echo State Network (ESN) against a Physics-

Informed Neural Network (PINN) constrained by the Lagrangian equations of mo-

tion, on closed-loop prediction of double-pendulum trajectories. All training data

are designed to match an undergraduate-lab-grade hardware platform: manual pen-

dulum release, a 60 fps consumer-phone camera, and initial states recovered from

video tracking (estimation uncertainty ≈ 0.5

◦
). We further implement a Hybrid

(Universal-Differential-Equation style) model fusing the analytical right-hand side

with a small residual network, and report results on both undamped and damped

(fitted joint damping, b ≈ 1.66 × 10−5 N·m·s/rad) ground truth.

Across 50 random initial conditions, with each model trained independently multi-

ple times (reporting the median of per-run medians to reflect training stochastic-

ity), models carrying stronger physical structure outperform the data-driven ESN

(median horizon 0.70 s on chaotic trials, 10◦
threshold): the fully-analytic-prior Hy-

brid reaches 2.85 s (≈ 4.1×), a pure-data MLP 1.55 s (2.2×), and the Lagrangian-

physics-loss PINN 0.88 s (1.3×). Normalized by the self-measured Lyapunov time

τL = 0.76 s, these are 0.91/1.15/2.03/3.74 τL for ESN/PINN/MLP/Hybrid, placing

our ESN baseline in line with the one-to-two Lyapunov times reported for reservoir

computing. Crucially, on 29 real double-pendulum videos under zero-shot sim→real

transfer, physics-prior models retain a clear advantage (Hybrid and PINN median

horizon ≈ 2.5–2.7× that of ESN, 0.167 s). The physics loss proves its worth precisely under distribution shift: with identical training, λphys = 0.1 raises the real median

horizon from 0.36 s (λphys = 0) to 0.42 s (≈ 1.16×), a gain absent in-simulation,

where clean-data fitting is most accurate. We further find the dominant driver of

sim→real transfer is simulation fidelity: a distributed-mass pendulum model match-

ing the real hardware transfers markedly better than an idealized point-mass model.

A three-ceiling error decomposition shows the short real horizon is governed primar-

ily by the model’s own approximation error, together with measurement noise and

initial-state uncertainty, rather than by the undamped model’s damping mismatch.

High-fidelity physical modeling together with physics-informed constraints substan-

tially extend the trustworthy prediction window for chaotic systems in low-cost

experimental conditions, with the physics loss’s value emerging precisely under

sim→real distribution shift, providing a feasible pathway for ML-assisted dynamics

prediction on undergraduate-lab-grade hardware.

Keywords: double pendulum; chaos; physics-informed neural network; echo state

network; Lyapunov time

目录

1 引言 | 6
2 物理模型 | 8
3 数值仿真基线 | 10
4 实验装置 | 10
5 视觉测量系统 | 13
6 机器学习模型 | 16

7 结果与分析 | 19
8 sim→real 迁移与误差成因分解 | 23
9 讨论与展望 | 28
10 结论 | 30
A 可复现性与代码 | 34
B 关键超参数 | 36
C 消融实验 | 36
D 方法论诚实性说明 | 39

## 1 引言

### 1.1 研究背景

混沌系统预测兼具理论深度与工程价值。大气是典型的高维混沌系统，数据驱动的

天气预报模型 GraphCast 与盘古气象已在多数指标上超越传统数值预报系统，并能在

分钟级时间内完成十天预报¹⁻²；而将物理定律作为先验约束嵌入学习模型的范式，也已

在更广的工程与环境系统中得到系统性梳理³。

双摆混沌动力学 双摆系统在 18 世纪被 Lagrange 系统研究，是最简单的能够呈现确

定性混沌的二自由度力学系统。Shinbrot 等人用照相法首次在实验上验证了双摆轨迹的

正 Lyapunov 指数特性⁴，Levien 与 Tan 设计了适用于本科教学的双摆装置以演示其对

初值的敏感依赖⁵，Stachowiak 与 Okada 用谱方法系统刻画了相空间中混沌区与准周期

区的边界⁶。Vitanov 等计算了双摆在不同能量层级下的最大 Lyapunov 指数 λmax，给出

Lyapunov 时间 τL = 1/λmax 的解析估算⁷。混沌系统之所以难以长时间预测，根源在于

初值的指数敏感性：两条邻近轨迹的状态距离按 e

t/τL 放大，无论初值精度多高，可信

预测都被限制在约 1 个 Lyapunov 时间之内，这是混沌动力学的经典结论⁸。

数据驱动预测：储池计算 Echo State Network（ESN）由 Jaeger 与 Haas 提出，用稀疏

随机循环网络的“储池”提取高维非线性特征，仅训练线性读出层⁹。Lu 等与 Pathak 等

系统研究了 ESN 在 Lorenz、Kuramoto-Sivashinsky 等混沌系统上的预测能力，给出“约

1–2 个 Lyapunov 时间”的视界基线¹⁰⁻¹¹。ESN 不利用任何物理先验，纯靠时间序列学习。

物理约束与混合建模 Raissi 等提出 Physics-Informed Neural Network（PINN），将偏微

分方程（partial differential equation, PDE）残差作为正则化项嵌入训练损失，使神经网

络在求解 PDE 时遵守物理约束¹²。针对哈密顿系统与拉格朗日系统，Greydanus 等提出

Hamiltonian Neural Network（哈密顿神经网络，HNN）¹³，Cranmer 等提出 Lagrangian

Neural Network（拉格朗日神经网络，LNN）¹⁴；这两类模型通过学习系统的能量函数，在

结构上保持能量守恒。Karniadakis 等在 Nature Reviews Physics 综述了该领域¹⁵。Chen

等提出的 Neural ODE（神经常微分方程）将动力学学习视为连续时间常微分方程的

求解¹⁶，Rackauckas 等进一步把已知物理方程与神经网络结合为 Universal Differential

Equation（通用微分方程，UDE）¹⁷，即本文所称的 解析-NN 混合范式。

本研究定位 现有文献大多在数值仿真层面对比这些方法，鲜有在低成本实物装置（本

科实验室级硬件、手动释放、手机相机视觉测量与初值反演）下做端到端的可预测窗

口量化。本文聚焦这一空缺，并开源全套可复现材料：硬件加工图与物料清单（bill of

materials, BOM）、全部软件，以及 29 段真实轨迹的分析窗数据集与由原始录像重建逐

帧结果的脚本（详 节 4 与 节 A）。更重要的是，双摆在本文中被用作一个可精确开关

物理先验的最小试验台：在同一套数据与评测口径下，把物理约束从无（纯数据 MLP）、

到弱（物理损失 PINN）、再到强（解析先验 Hybrid）逐级注入，使我们得以在受控条

件下诚实回答物理约束何时有用、增益有多大，而非停留在单一模型的点对比。

### 1.2 研究问题

核心问题：在本科实验室级的测量精度下（相机 60 fps、初值状态估计不确定度约

0.5

◦），为神经网络引入物理约束，能否显著延长它对混沌轨迹的可信预测窗口？

### 1.3 本文贡献

1. 设计并实现了一套总成本约 580 元的双摆实验装置（详 节 4），设计目标为摆轴衰

减时间常数 τ ≥ 30 s，实测达 τ ≈ 130 s（约 4× 目标，见 节 4），以提供 AI 训练所

需的“干净”混沌窗口；

2. 对比 ESN、纯数据 MLP、PINN（拉格朗日物理损失）与 Hybrid（解析先验 + 残

差）四类模型，在相同训练 / 预测设置、多次独立训练下量化物理结构的贡献；

3. 揭示 sim→real 零样本迁移的两个关键：仿真保真度（与真实硬件一致的分布质量

建模）为首要驱动，物理损失作为分布迁移下的稳健性正则提供二阶增益（在同分

布仿真内反而无益）；

4. 在初值不确定度上进行敏感性扫描（节 7.3），以解析真解为纯净参照，分离出混沌

放大与模型逼近误差各自的贡献，并给出约 ±0.5

- 初值不确定度下本研究结论的退

化幅度。

### 1.4 论文结构

节 2 给出双摆拉格朗日动力学；节 3 介绍数值基线；节 4 描述硬件平台；节 5 给出

视觉追踪管线；节 6 介绍 ESN、Hybrid 与 PINN 三类模型；节 7 给出仿真内的对比结果

与初值敏感性扫描；节 8 是本文的核心部分，报告 29 段真实轨迹上的零样本 sim→real

迁移、物理损失的价值边界，以及真实短视界的三天花板误差分解；节 9 讨论局限与展

望；节 10 归纳结论。附录中，节 A 给出完整的复现入口与目录结构，节 B 列出各模型

关键超参数，节 C 报告消融实验，节 D 记录方法论上的自我修正。

## 2 物理模型

### 2.1 拉格朗日方程

双摆是非线性振动理论中的经典强耦合系统¹⁸。本研究的实物为分布质量物理摆¹⁹：

上下摆杆是质量沿杆身分布的刚性铝臂，下摆末端另加配重，质量并非集中于杆末端的

理想质点。故以各摆的总质量 Mi、质心到其转轴的距离 Lc,i，以及绕转轴的转动惯量建

模——上摆绕固定顶轴 O 的转动惯量记 I
O

1 ，下摆绕关节轴 A 的转动惯量记 I
A

2 。设关

节间距（顶轴到关节）为 L1，下摆几何长度为 L2，两摆杆与竖直方向夹角分别为 θ1, θ2

（图 1）。

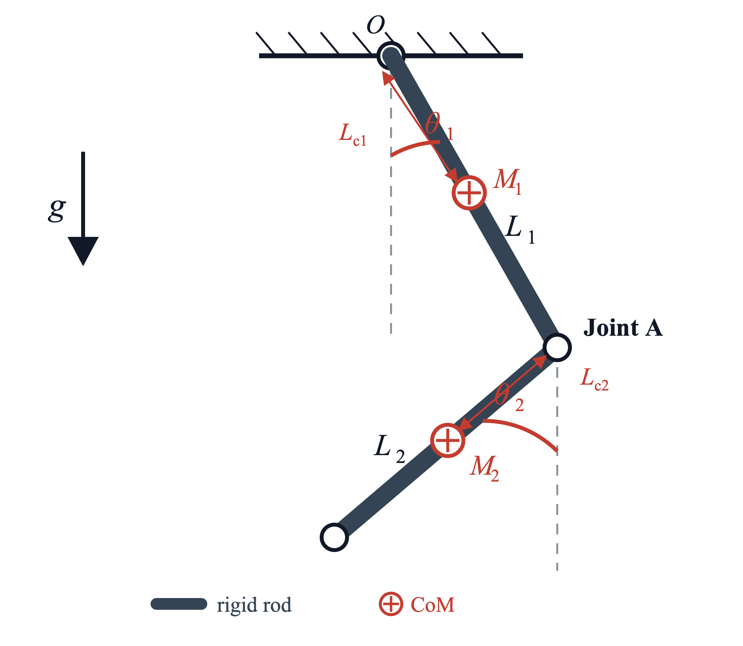
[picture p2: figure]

图 1: 双摆物理模型示意图。两摆杆按分布质量刚体建模：M1, M2 为各摆总质量，Lc1, Lc2 为 质心到相应转轴的距离，L1, L2 为几何长度，θ1, θ2 为两摆与竖直方向的夹角，g 为重力加速度。

拉格朗日量

L = T − V | (1)

其中动能与势能为（下摆动能已用平行轴定理 I
A
2 = I

cm
2 | + M2L
| 2

c2 合并）

T =

1/2(
I

O
1 + M2L

2/1)

˙θ1

2
+ M2L1Lc2 cos(θ1 − θ2)

˙θ1

˙θ2 +
1/2 I

A
2

˙θ2

2
(2)
V = − (M1Lc1 + M2L1) g cos θ1 − M2Lc2 g cos θ2 | (3)

应用 Euler–Lagrange 方程
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
得到运动方程的矩阵形式

M(θ) θ¨ = b(θ, θ˙) | (4)

其中质量矩阵与力向量为

M(θ) =

I

O
1 + M2L

2
1 | M2L1Lc2 cos(θ1 − θ2)
M2L1Lc2 cos(θ1 − θ2) | I

A
2
(5)

b(θ, θ˙) =

−M2L1Lc2 sin(θ1 − θ2)

˙θ2

2
− (M1Lc1 + M2L1)g sin θ1

M2L1Lc2 sin(θ1 − θ2)

˙θ1

2
− M2Lc2 g sin θ2
(6)

质量集中于杆末端的理想点质量摆是本式的特例（Lc1 = L1, Lc2 = L2, IO 1 = M1L

2/1, IA
2 =

M2L

2

2）。本研究按实测物料清单（BOM，见 diagrams/parts/BOM.md）反推分布质量参

数：L1 = 250 mm, L2 = 200 mm，总质量 M1 ≈ 96.5 g, M2 ≈ 139 g，质心距 Lc1 ≈ 122 mm,

Lc2 ≈ 145 mm，转动惯量 I
O

1 ≈ 1.99×10−3 kg m²
, I

A

2 ≈ 3.54×10−3 kg m²，g = 9.81 m/s²。

采用与真实硬件一致的分布质量模型，是后文 sim→real 零样本迁移得以成立的关键（见

节 8.3）。具体实现见 sim/baseline.py，符号求逆得到 θ¨ = M−1b。

### 2.2 混沌特征：最大 Lyapunov 指数实测

我们对 50 组随机初值（θ1, θ2 ∈ [−90◦

, 90◦
] 均匀采样，ω = 0 静止释放）实施基于轨

迹分叉的最大 Lyapunov 指数估算：对每组参考初值施加 ε = 10−6 rad 扰动，跟踪两条

由 RK45（四/五阶 Runge–Kutta 自适应步长法）积分得到的轨迹之间的 4 维相空间欧

氏距离 d(t) 在 3 s 内的指数增长，对数线性区拟合得到斜率 λmax。50 组随机初值中 48

组有效拟合（另 2 组分叉斜率非正剔除）的分布（分布质量模型）：均值 λ¯max = 1.21 s −1

（1/λ¯max = 0.83 s），中位 λ
med
max = 1.31 s

−1（τ

med
L = 0.76 s）。方法学注：此处 τL = 0.76 s

取自分叉曲线 0.15–1.5 s 区间的对数线性拟合，反映的是保守的短期分叉率而非严格的

最大 Lyapunov 指数（后者需 Wolf 算法配合重整化跟踪到长时极限⁷）；本文仅以它作

为归一化基准，物理先验模型相对 ESN 的提升这一核心结论并不依赖该值的绝对大小。

该结果显著低于文献在高能量混沌区给出的 λmax ∼ 5–10 s

−1 （τL ∼ 0.1–0.2 s）⁷，但这种

差异在物理上是合理的：本研究的静止释放对应较低能量级，其局部 Lyapunov 指数较

小；高能量区的文献数值适用于含初始角速度的高能轨迹。本研究后文所有视界归一化

均采用自测中位值 τL = 0.76 s。

## 3 数值仿真基线

### 3.1 数值方法

我们采用 SciPy solve_ivp 中的 RK45 自适应步长积分器求解 式 (4)，相对容差取

10−10、绝对容差取 10−12。为检验积分精度，我们对 50 组 30 s 仿真进行能量守恒校核：

总能量的最大相对漂移为 8.8 × 10−9、均值为 7.0 × 10−10，均处于机器精度量级。

### 3.2 蝴蝶效应可视化

两条初值差 0.1

- 的轨迹在前 3 s 几乎重合，随后呈指数分叉（图 3）。这印证了 节 1

提出的初值敏感性结论。

## 4 实验装置

### 4.1 机械设计

装置正视装配图见仓库 diagrams/02_mechanical_front_view.svg，关键尺寸与

材料：

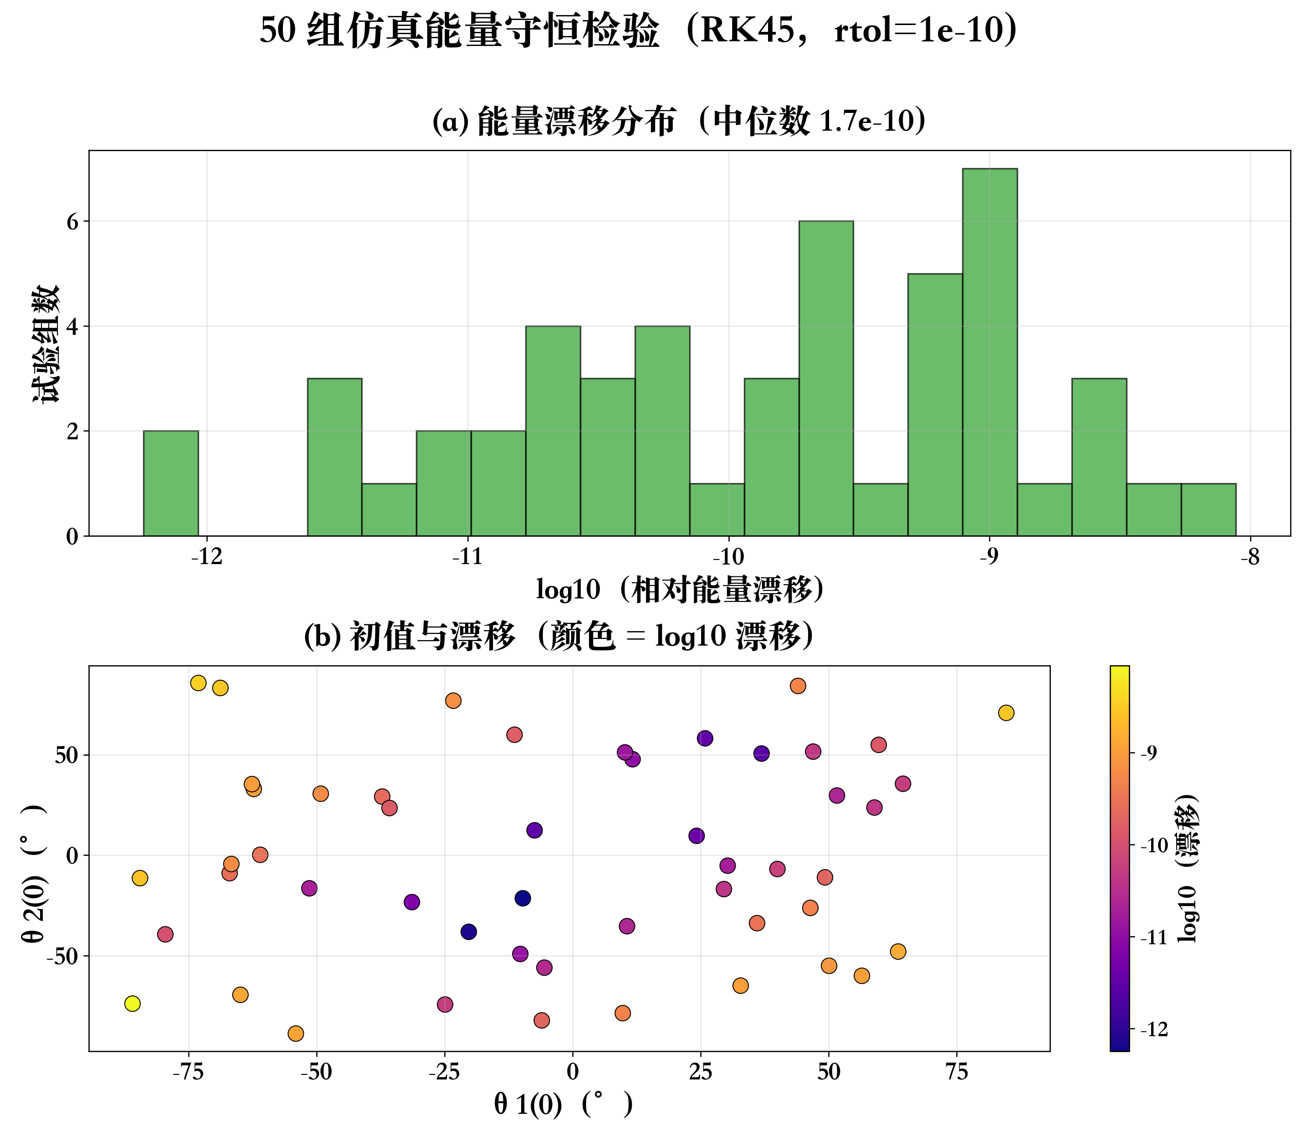
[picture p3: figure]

图 2: 50 组 30 s 仿真总能量相对漂移 |E(t) − E0|/|E0|，最大值 8.8 × 10−9。RK45 + 严格容 差下能量守恒在机器精度量级。

- 摆长：L1 = 250 mm，L2 = 200 mm（非对称避免简正模退化）
- 摆臂：6061-T6 铝板，4 mm 厚（匹配 MR105ZZ 轴承宽度 4 mm）
- 主轴承：MR105ZZ 微型深沟球轴承，工业酒精脱脂去除厂润滑脂，单滴 MOEBIUS

9020 钟表油重新润滑

- 配重盘：45# 碳钢 ∅30 × 12 mm，66 g
- 主轴座：6061-T6 5 mm 厚，∅5 H7 轴孔 + 2 个 M5 安装孔
- 框架：2020 国标铝型材，T 槽螺母拼接

材料 + 加工件 + 视觉件总采购成本约 580 元（详 diagrams/parts/BOM.md）；其中背

板与标记两项视觉件按设计方案计入，实拍 29 段实际采用的是更易得的替代方案（见


图 3: 蝴蝶效应（分布质量拉格朗日模型）：仅将 θ1(0) 从 60.0

- 改为 60.1

◦，其余初值均保持
θ2(0) = 0◦、ω1(0) = ω2(0) = 0。(a) 两条 θ1 轨迹前期几乎重合，随后分叉；(b) 分别给出两摆 角度偏差的绝对值（对数纵轴）。初始时 |∆θ1| = 0.1

◦、|∆θ2| = 0◦；后者的零值以 10−4 ◦ 的显 示下限绘制。首次满足 max(|∆θ1|, |∆θ2|) > 10◦ 的时刻为 7.40 s。

节 5）。

### 4.2 初值设定与不确定度

本研究的真实轨迹由手动将下摆抬至目标角度后释放产生，释放角度不作精确机械

控制。关键在于：每段真实轨迹输入模型的初始状态 (θ1, θ2, ω1, ω2) 并非取自释放动作

的标称角度，而是由视觉追踪从释放后的引入窗中反演得到（见 节 5 与 节 8.1）。因此

模型预测所依赖的是初始状态的视觉估计精度，而非释放动作的机械重复性——手动释

放引入的微小初始角速度也被追踪如实捕获，一并纳入初始状态。节 8.3 的误差分解实

测该初值状态估计噪声为角度 σθ ≈ 0.45◦、角速度 δω ≈ 0.09 rad/s，约相当于 ±0.5

- 量

级；该不确定度对预测视界的影响经敏感性扫描（节 7.3）量化：在该量级下 PINN 中

位视界退化约 10%，本文结论不受影响。

### 4.3 衰减测试

为保证机器学习训练所需的“干净”混沌窗口，装置主轴承应满足单摆 30◦ 释放衰减

时间常数 τ ≥ 30 s。脱脂 + 钟表油润滑方案的衰减指标由下文实物测试直接验证。实物

衰减测试已完成：单摆 90◦ 释放、重复两次，振幅自 90◦ 衰减至约 1–2

- 历时约 551 s（两次

分别 552.0 / 550.8 s，重复性 0.2%）；按指数包络 A(t) = A0e

−t/τ 估算等效衰减时间常数

τ ≈ 130 s（随终止振幅取值在 122–145 s 区间），约为设计目标的 4 倍，满足 τ ≥ 30 s（实测

在 90◦ 大幅释放下进行、含较强空气阻力，相对 30◦ 设计口径为保守下界，30◦ 释放的 τ 只

会更大）。该等效 τ 对应单摆主轴承等效粘性 b ≈ 2Ieff/τ ≈ 1.7×10−4 N·m·s/rad（手计时

等效估计，90◦ 大幅释放含较强空气阻力，为保守上界）。双摆运行工况下的关节阻尼则另

由 16 段实测追踪轨迹按能量耗散率法拟合（sim/fit_damping.py，详见 节 8.3），分离为

粘性 b ≈ 1.66×10−5 与二次空气阻力 c ≈ 8.72×10−6（空气阻力约占总耗散 78%，逐段 R²

实测在 0.95–0.999 区间、中位 0.986，见 data/sim_damped/fit_damping_report.csv）。

对单摆等效转动惯量 Ieff ≈ 1.1 × 10−2 kg·m²，τ ≥ 30 s 目标对应阻尼系数上界 b ≤

2Ieff/(30 s) ≈ 7 × 10−4 N·m·s/rad（实测等效 b ≈ 1.7 × 10−4 在此上界之内）。我们在

sim/baseline_damped.py 中实现了带粘性 + 二次空气阻力两项的仿真版本作为 v3 真

值，默认即采用上述实测拟合系数 b ≈ 1.66 × 10−5、c ≈ 8.72 × 10−6（不再用占位值），

亦可经命令行参数覆盖。

## 5 视觉测量系统

### 5.1 相机配置

采用消费级智能手机后置摄像头以 60 fps 拍摄（数据集统一采用 60 fps 长时连续录

像；机型亦支持 120 fps 慢动作，仅用于早期测试，未纳入分析数据集）。本装置下摆

的小摆动频率按点质量近似为 √
g/L2/2π ≈ 1.1 Hz；混沌大幅甩动下的瞬时角速率远高

于此。由 29 段正式追踪结果（data/tracking/tracked_*.csv，共 411 746 帧）回算，

max(|ω1|, |ω2|) 的全库峰值为 25.8 rad/s，折合 4.11 Hz；逐段峰值的中位为 3.19 Hz，折

合频率超过 3.2 Hz 的帧仅占 0.04%。以实测全库峰值 4.11 Hz 计，60 fps 约为 15 倍过采

样（相对 8.2 Hz 的 Nyquist 采样下限约为 7 倍）；该峰值处单帧角度增量约 24.7

◦，远

小于相位解卷绕失效所需的 180◦，采样充分。相机固定于三脚架，光轴近似垂直于摆

动平面，录制分辨率 1920 × 1080；由标定内参（fx/W ≈ 0.81，水平视场角约 63◦）与

下述像素标度反推，工作距离约 0.9 m。以正式 29 段追踪结果中 m1–m2 像素间距的中

位（353 px）对下摆长 L2 = 200 mm 定标，得有效像素标度约 0.57 mm/px，对应视野约

1.1 × 0.6 m。

### 5.2 追踪算法

上下摆铰接处与下摆末端各贴一枚方形彩色贴片作为视觉标记：铰接处记 m1（蓝

色），末端记 m2（浅红色）；两枚标记在实拍打光下均无镜面高光，末端标记成像偏粉、

饱和度偏低。正式 29 段中 m1、m2 的连通域面积中位分别约 370 与 650 px，按上述

0.57 mm/px 折合等效直径约 12 与 16 mm。拍摄背景为置于摆后方的深色织物，画面两

侧仍可见浅色墙面。diagrams/parts/BOM.md 中列出的哑光黑亚克力背板与 ∅5 mm 反

光圆点标记属装置设计方案，本文 29 段实测录像未采用，正文各处均以上述实拍状态

为准。实拍追踪管线（tracking/track_pendulum.py）流程：

1. 帧 BGR 色彩通道（蓝、绿、红）→ HSV 色彩空间（色相、饱和度、明度）
2. 红色区间 + 蓝色区间各自做 inRange 阈值分割（红色由于跨越 H=0◦ 用双段并集）
3. 形态学开 + 闭运算（半径 5 的椭圆核）去噪
4. connectedComponentsWithStats 取全部面积超过 MIN_AREA 的连通域作为候选（合

成视频验证脚本 track.py 在此直接取最大连通域）

5. 像素轨迹 → 物理坐标（自动标定：m1 轨迹最小二乘拟合圆得支点与 L1 像素半径）
6. 反解角度：θ1 = atan2(x1, −y1)，θ2 = atan2(∆x, −∆y)

保留全部候选、再交由双向 Viterbi 选轨，是本管线与逐帧取最大连通域这一常见

做法的主要差别。实拍画面中的同色干扰并不罕见：作为背景的深色织物在相机中

成像偏藏青、色相落入蓝色区间——若仅把明度门限退回脚本默认（--blue-vmin

40，饱和度与空间门限仍取正式参数），29 段每帧的蓝候选中位便涨到 27–76 个

（全库中位 41 个，其中 IMG_1448 段为 46 个，与下文消融一致；逐段统计见 tools/count_blue_candidates.py，结果落盘于 data/tracking_ablation/），织物褶

皱与底边缝线处尤其容易形成不随摆动移动的常驻斑点，面积有时还大于真标记；暖色

墙面与释放瞬间入镜的手则会落进红色阈值。其中个别干扰恰好还位于距末端标记约 ℓ

处——此时仅凭刚性距离无从判别。我们在 IMG_1448 段（13 153 帧）上对选轨策略

做了消融（tools/ablation_transition_cost.py，两种策略共用同一批检测候选，差

别仅在转移代价系数）：沿用脚本默认的低明度门限时，每帧蓝候选中位达 46 个（最

多 67 个），只用刚性距离约束有 9 123 帧（69%）选到与联合判别不同的候选，m1 圆拟

合 RMS 残差为 133 px；补上帧间位移的转移代价后残差降至 43 px。但二者均远超下

文 10 px 的合理性门槛，说明时序连续性能大幅压制同色假阳性、却并不能挽救一个取

错的阈值——这正是本管线在阈值标定之外还要设硬性合理性检查的原因。而在抬高明

度门限后的正式参数下，每帧蓝候选中位降至 1 个、仅 9 帧出现多候选，两种策略选出

的轨迹完全一致（RMS 均为 0.42 px），此时刚性约束已单独够用。可见转移代价的价值

随假阳性密度而变，两条准则联合使用才能在参数偏离时仍保持鲁棒。

阈值随场景标定：正式数据集 29 段共用同一套 HSV 阈值（蓝色明度门限 V ≥ 160、

饱和度门限 S ≥ 55 与右侧空间门限），仅时间窗逐段不同；抬高蓝色明度门限正是为了

把偏藏青的背景与实测明度约 240 的高亮蓝标分开。阈值取错时管线不会报错，而会给

出自洽却错误的结果（命中率与帧间平滑度等内建指标仍全部正常，支点却被拟合到画

面之外），故在写出结果前设三项硬性合理性检查：支点须落在画面内、圆拟合 RMS 残

差须 ≤ 10 px、ℓ/r 须落在设计值 L2/L1 = 0.80 的 ±25% 以内，任一不满足即拒绝写盘。

29 段的完整复现命令留档于 tracking/reproduce_29.sh，据此重跑所得 CSV 与本文

所用追踪结果逐字节一致（已抽取其中 5 段核对 MD5）。脚本另备一条 Lab 色彩空间

的检测分支（--detector lab）以适配不同配色的标记，本文 29 段数据全部采用上述

HSV 分支。

角度定义与几何反演的精度在 data/sim/figures/anim_trial_000.mp4（30 fps 合

成动画，真值已知）上验证——该合成片段由 tracking/track.py 追踪，与实拍脚本共

用同一套角度定义与自动标定几何——跟踪角度中位误差 θ1 : 0.12◦

, θ2 : 0.15◦，90% 分

位误差 0.25–0.35◦。该结果表明追踪算法在干净图像上误差极小；真实拍摄下初值状态

的估计噪声更高（约 0.45◦，见 节 8.3），主要来自实拍光照、反光与运动模糊，构成真

实视界的主要可改进来源之一。

### 5.3 标定与精度

相机内参用 OpenCV 的 calibrateCamera²⁰（基于 Zhang 平面标定法²¹）在 7×9 棋盘

格上标定。仓库内存有两套标定：29 段 canonical 追踪结果由 camera_params.npz（五参

畸变模型）产出，这也是 tracking/track_pendulum.py 默认加载的标定；此外还有一次

后做的重标定 camera_params_ 新标定.npz（14 张有效标定图，固定 k3 = 0 的四参模型，

平均重投影误差 0.44 px），未用于产出本文数据。为确认结论不依赖标定的选取，我们把

两套标定分别作用于 29 段的标记点轨迹并反演角度（tools/calib_sensitivity.py）：

扣除两者主点差异造成的整体常数偏置后，逐帧角度残差的逐段中位为 θ1 0.10◦、θ2 0.22◦，

均小于约 ±0.5

- 的初值状态估计不确定度（节 8.3），故标定选取对本文结论无实质影

响。摆的运动平面与相机光轴近似垂直，且角度反演只取像素差的比值、与整体像素标

度无关，因此无须把像素轨迹换算为米制即可得到角度。实测亦支持这一处理：29 段中

m1–m2 像素间距在整段内的相对波动（标准差/中位）中位为 1.2%、最大 1.6%，说明

投影标度全程近似恒定，面外运动与透视效应造成的标度变化处于同一量级。

## 6 机器学习模型

### 6.1 回声状态网络（ESN）基线

ESN 的核心思想是用稀疏随机循环网络（“储池”）将输入投影到高维非线性特征空

间，仅训练线性读出层⁹。本研究 ESN 配置：

- 储池规模 Nres = 800
- 谱半径 ρ(W) = 0.95（接近临界，满足回声状态性质）
- 漏率 = 0.25，稀疏度 0.1
- 输入编码：状态 (θ1, ω1, θ2, ω2) 映射为 (sin θ1, cos θ1, ω1/10,sin θ2, cos θ2, ω2/10) 6 维

向量

- 读出层用岭回归 α = 10−5 求解，washout 200 步

上述为仿真侧配置。真实数据侧每段仅有 4 s 引入窗可供自训练，为避免小样本下的过

拟合，ESN 基线改用规模更小的储池（Nres = 300、漏率 0.3、α = 10−3、washout 50，见

rc/real_validation_multi.py）。为排除“人为削弱基线”的疑虑，我们把上述仿真侧配

置连同一个四因子超参网格（储池规模、谱半径、漏率、岭系数）同样在 29 段真实数据上完

整跑过一遍（tools/esn_grid_real.py，结果见 data/esn_grid_real/summary.md）：在

本文所用的 4 s 引入窗下，仿真侧配置给出的 ESN 中位视界为 ≥ 0.167 s、网格最优配置

为 ≥ 0.183 s（“≥”因部分片段右删失，中位为下界），均仍显著低于同一单次运行口径下的

PINN 0.417 s 与 Hybrid 0.484 s（seed 42，data/real_validation/summary_multi.csv；

表 3 报的是 8 次独立重训的逐次运行中位）；作为同口径参照，真实侧配置本身在该网

格下为 ≥ 0.150 s。可见本文结论不依赖 ESN 配置的选取。

物理先验的优势边界：引入窗越长，纯数据基线越强 同一份网格扫描还沿引入窗长

度 Tlead ∈ {2, 4, 8, 16, 32} s 做了二维展开，回答一个自然的追问——纯数据 ESN 需要

每段多少秒实测数据现场自训练，才能追平一秒真实数据都不用的零样本物理模型。

在预测窗同为 4 s 的口径下，网格最优 ESN 的中位视界随 Tlead 由 0.150 s（2 s）增至

≥ 0.183（4 s）、≥ 0.534（8 s）、≥ 1.234（16 s）、≥ 3.735 s（32 s），而 Hybrid 相应

为 0.600/0.484/0.717/1.000/1.267 s：在本文所用的 4 s 引入窗下物理先验占优约 2.6 倍，

Tlead = 16 s 附近纯数据基线反超，32 s 时已明显领先。我们如实报告这一交叉，并据此

把本文的结论限定在其成立的条件上：物理先验的价值出现在真实数据稀缺的一侧——

每段只有数秒可用历史时，把已知方程放进模型远比让网络从这几秒里学动力学更有

效；一旦每段可获得数十秒的实测数据，纯数据方法自会追上并超过。这正是低成本、

短录制场景（也是本文的目标设定）最关心的区间。需说明的是，长引入窗档的中位数

受右删失影响较大（Tlead = 32 s 时删失率达 48%），其数值为下界，故上述交叉点的

位置只宜作量级判断。逐档完整结果见 data/esn_grid_real/summary.md。完整实现见

rc/esn.py（约 290 行）。

### 6.2 物理-数据混合模型（Hybrid）

为评估“已知物理 + NN 残差”范式在本任务上的价值，我们实现了 Universal Dif-

ferential Equation 风格的 Hybrid 模型¹⁷：

ω˙ Hybrid(θ, ω) = ω˙ baseline(θ, ω) + s · MLP(θ, ω) | (7)

其中 ω˙ baseline 为 式 (4) 给出的解析方程右端项（right-hand side, RHS），s 为残差缩放

因子。MLP 末层权重采用 xavier_normal 初始化（gain = 0.01），并取很小的初始幅

度，保证初始预测约等于解析先验。Hybrid 的训练损失与 PINN 同构（式 (8)），同为数

据项与拉格朗日物理残差项的加权和，取 λphys = 0.5、配点数 1024、batch 512、Adam

学习率 1 × 10−3 配余弦衰减，训练 200 epoch。因解析先验已承担右端项的主体，网络

只需学一个很小的残差，物理残差项在训练早期即接近零；该权重在此的作用是约束残

差不把解推离物理可行流形，而非像 PINN 那样承担物理信息的主要注入。完整实现见

rc/hybrid.py。

### 6.3 物理约束神经网络（PINN）

网络结构 MLP，6 维输入 → 128 单元 ×4 隐层 → 2 维输出（ω˙ 1, ω˙ 2）。输入采用极坐

标编码 (sin θi
, cos θi

, ωi/Wscale)，输出归一化 ω˙ /Ascale，其中 Wscale = 10，Ascale = 100。

损失函数 数据项 + 物理项的加权和

L = Ldata + λphys Lphys | (8)

其中物理残差直接从 式 (4) 推出

Lphys = ∥M(θc) ω˙ NN(θc, ωc) − b(θc, ωc)∥

2
(9)

每个 epoch 均重新采样 2048 个配点（即用于计算物理残差的状态点）(θc, ωc)。

训练 训练 300 个 epoch（完整遍历训练集的轮次），采用 Adam（自适应矩估计）优化

器，初始学习率为 2 × 10−3，并使用余弦衰减。算法 1 给出完整训练流程。

Algorithm 1 PINN 训练循环（rc/pinn.py 实现）
Require: 训练数据 {(s

(i)
, ω˙

(i)
)}

N

i=1（来自 trial 0-4 前 20 s）
Require: 网络 fϕ : R

4 → R
2，损失权重 λphys，配点数 Nc
Ensure: 训练后的网络参数 ϕ

∗
1: for epoch = 1 to 300 do
2: | for 每个 mini-batch B（batch size 512） do
3: | 从训练集采样 (sb, ω˙ b) ∈ B
4: | 从相空间 θ ∈ [−π, π]
2

, ω1 ∈ [−20, 20], ω2 ∈ [−25, 25] 均匀采样 Nc = 2048 个 配点 {sc}
5: | ω˙

pred
b ← fϕ(sb)； ω˙

pred
c | ← fϕ(sc)
6: | Ldata ← ∥(ω˙

pred
b − ω˙ b)/Ascale∥

2
7: | Lphys ← ∥M(θc) ω˙

pred
c − b(θc, ωc)∥

2

8: | L ← Ldata + λphys · Lphys
9: | ϕ ← Adam(ϕ, ∇ϕL)
10: | end for
11: | 更新余弦学习率
12: end for
13: return ϕ

闭环预测 用 RK4（四阶 Runge–Kutta 法）积分 s˙ = [ω1, ω˙ 1, ω2, ω˙ 2]，ω˙ 由训练好的 fϕ∗

给出，时间步 ∆t = 1/120 s。

## 7 结果与分析

### 7.1 评测协议

全文以可信预测视界为唯一评测指标，定义为闭环预测的角度偏差首次超过阈值的

时刻

h = min {
t :

√
∆θ1(t)

2 + ∆θ2(t)

2 > 10◦

}
, ∆θi = atan2(sin δi

, cos δi), δi = ˆθi − θi

(10)

其中 ˆθi 为预测角，θi 为解析积分或视觉追踪给出的真值角；atan2 形式用于消除角度的

2π 周期歧义。若整个评估窗内偏差始终不超阈，则记视界为窗长并标注为右删失，该值

为真实视界的下界。仿真内与真实数据两侧共用同一实现，仅评估窗长不同（仿真 10 s、

真实 4 s）。图 3 的蝴蝶效应示意为便于逐轴读图另用 max(|∆θ1|, |∆θ2|) > 10◦ 判据，其

7.40 s 与本节各表不属同一口径，不作横向比较。10◦ 阈值本身的稳健性核验见 节 D。

### 7.2 可信预测视界

仿真内的训练与评测按如下口径划分：PINN、纯数据 MLP 与 Hybrid 三者仅以

trial 0–4 前 20 s 的状态与加速度样本训练一次，随后在全部 50 组随机初值（trial 0–49）

第 20 s 处以真值状态为起点闭环外推 10 s，其中 45 组为训练中未出现过的轨迹；ESN

则是逐段自训练的时序模型，对每个 trial 单独以其前 20 s 训练读出层，再预测同一 trial

随后的 10 s。此口径对 ESN 有利——它拿到的是待预测轨迹本身的历史，而三个网络模

型只拿到一个初始状态；物理先验模型在此不利口径下仍占优。需说明的是，trial 0–4

的预测段虽与其训练段在时间上不重叠，但仍取自训练所用的同一批轨迹，故 50 组评

测中有 5 组并非严格的样本外评估。每个模型均在自身的混沌子集（视界 < 9.9 s）上

取中位数，以排除少数落入或被预测为长周期轨道的试验样本（trial）；其中三方模型

（ESN / PINN / Hybrid）一致判定为混沌的样本共 N = 32（图 4 所用子集）。统计结果

列于 表 1。

表 1: 50 组完整扫描·混沌 trial（每次运行取视界 < 9.9 s 子集）闭环预测视界统计（10◦ 阈 值）。每个模型独立训练多次（ESN 更换储池随机种子 ×10；PINN/Hybrid 非确定性重训 ×8），报告逐次运行中位的中位数及四分位距 [IQR]。

模型 | 视界中位 (s) | IQR (s) | 归一化 /τL | 相对 ESN
ESN（数据驱动基线） | 0.70 | [0.55, 0.70] | 0.91 | 1.0×
PINN（λphys=0.1） | 0.88 | [0.77, 1.03] | 1.15 | 1.3×
纯数据 MLP（λphys=0，消融） | 1.55 | [1.31, 1.68] | 2.03 | 2.2×
Hybrid（解析先验 + 残差） | 2.85 | [2.12, 3.27] | 3.74 | 4.1×

倍数为各模型逐次运行中位数之比。Hybrid 与纯数据 MLP 明显超过数据驱动的 ESN 基线，PINN 亦高 于 ESN 但幅度有限；其中解析先验最完整的 Hybrid 在仿真内最强。带物理损失的 PINN（λ=0.1）仿真 内中位（0.88 s）低于无物理损失的纯数据 MLP（1.55 s）——在干净、无噪的仿真数据上纯数据拟合本 就最准，物理损失在此略有代价；其真正价值体现在 sim→real 零样本迁移（见 节 8.3）。ESN 行取修正 后的值：早先的闭环实现中，预测入口的储池起跑点与训练契约相差一个储池步——训练时状态 X[t] 已 消费输入 U[t]，而闭环入口又把该帧重喂了一次——致使 ESN 在预测窗第 0 帧即带约 2

| | | | ◦ 的角度偏差
（修正后降至 10−3 度量级），中位视界被压至 0.40 s。按训练契约对齐起跑点后 ESN 升至 0.70 s，相对倍 数相应由 2.2/3.8/7.0 修正为 1.3/2.2/4.1。新旧实现的逐位等价验证与逐 trial 对照见 tools/esn_closedloop_fix.py。真实侧的 ESN 调用本就与训练契约一致，表 3 的数字不受影响。

以自测 τL = 0.76 s 归一化，纯数据驱动的 ESN 可维持约 0.91 τL 的可信预测——这与文

献给出的“约 1–2 个 Lyapunov 时间”的储池计算基线相符¹⁰⁻¹¹，表明本文的 ESN 基线处

于合理水准而非被削弱；引入物理结构后，Hybrid 视界扩展到约 3.7 τL（相对 ESN 约

4.1 倍），纯数据 MLP 约 2.0 τL（2.2 倍），带拉格朗日物理损失的 PINN 约 1.2 τL（1.3

倍）。物理先验模型相对 ESN 的提升是本研究在仿真内的核心结论，独立于 τL 的绝对

值估算。所有数字均为多次独立训练得到的逐次运行中位数及四分位距，以反映训练随

机性。三方完整分布如 图 4 所示。

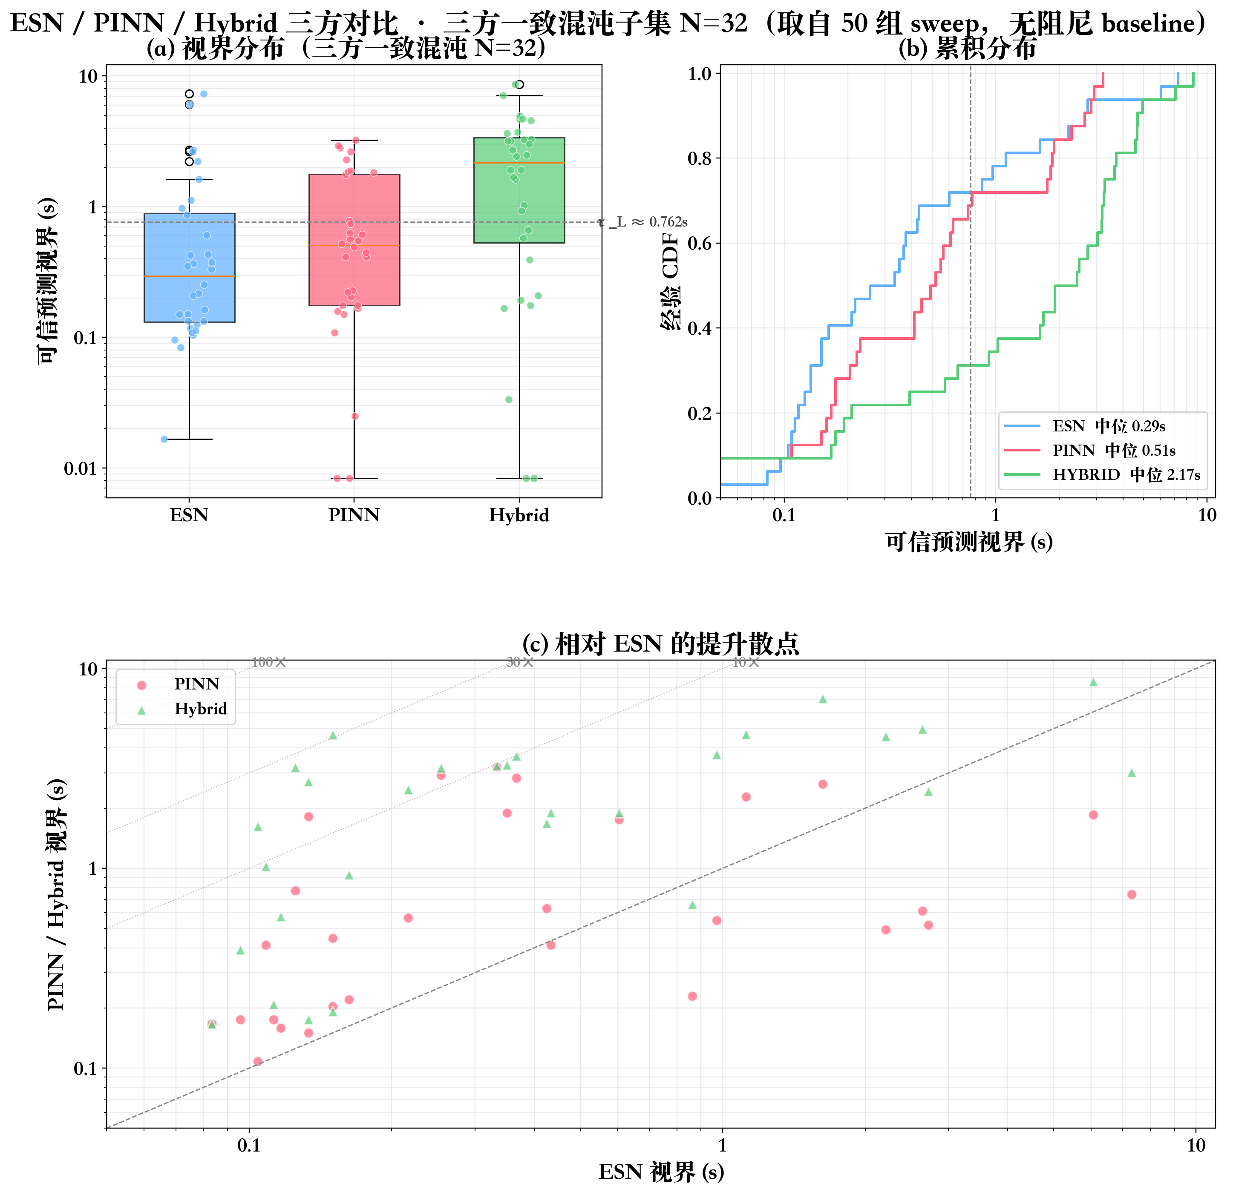
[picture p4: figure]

图 4: ESN / PINN / Hybrid 三方对比三联图。(a) 三方视界箱线图（对数纵轴）；(b) 经 验累积分布函数（cumulative distribution function, CDF）；(c) 散点图：横轴为 ESN 视 界，纵轴为 PINN / Hybrid 视界。N = 32 个三方一致的混沌样本。这是固定一次训练的逐 trial 可视化，故中位数为 ESN ≈ 0.29 s / PINN ≈ 0.51 s / Hybrid ≈ 2.17 s；表 1 则报告 多次独立训练的逐次运行中位数。两者口径不同，图中数值不用于替代表中统计。本图的 ESN 曲线取自修正前的闭环起跑点（见 表 1 脚注），仅用于展示三方视界的分布形态与逐 trial 相关 性，不用于支撑任何倍数结论；按修正路径重算后 ESN 的分布整体右移，Hybrid 相对 ESN 的逐 trial 优势仍然成立。
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

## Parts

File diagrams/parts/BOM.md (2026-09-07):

# ChaoticNet 双摆装置 物料清单 BOM

**版本**：v2（2026-06-11，含 9 点评审同步 + 摆臂改 4mm）
**总预算估算**：节省版 320-450 元 / 完整版 580-750 元（不含三脚架/手机）

---

## A. 加工件（给加工厂的）

每件都有独立加工图 SVG + DXF，直接发给厂家即可（淘宝搜"激光切割加工"或本地金属加工小厂）。

| 编号 | 名称 | 材料 | 数量 | 加工图 | DXF 文件 | 加工方式 | 预估单价 |
|---|---|---|---|---|---|---|---|
| P01 | 摆臂 1 | 6061-T6 铝板 4mm | 1 | `P01_arm_1.svg` | `dxf/P01_arm_1.dxf` | 激光切割 + ⌀10 孔绞孔 | 60-90 元 |
| P02 | 摆臂 2 | 6061-T6 铝板 4mm | 1 | `P02_arm_2.svg` | `dxf/P02_arm_2.dxf` | 激光切割 + ⌀5 孔绞孔 | 50-80 元 |
| P03 | 配重盘（v2.1: 45# 钢，⌀30×12mm） | 45# 碳钢 ⌀30 圆棒 | 1 | `P03_brass_weight.svg` | `dxf/P03_brass_weight.dxf` | 车削 + M3 通孔螺纹 + 喷透明防锈漆 | 8-15 元 |
| P04 | 主轴座 | 6061-T6 铝板 5mm | 1 | `P04_pivot_bracket.svg` | `dxf/P04_pivot_bracket.dxf` | 激光切割 + ⌀5 H7 绞孔 | 30-50 元 |

**加工件小计**：170-250 元

**设计注记**：P01/P02 摆臂的 ⌀10 孔单边距 7.5mm（孔径的 0.75 倍，机械手册推荐 ≥ 1×D）。本项目低载荷场合可接受，评委如问可答"6061-T6 屈服 276 MPa，孔边集中应力远小于强度极限"。激光切割时让师傅切完去毛刺别用大力，避免回火区域应力集中。

### 给加工厂打招呼的话术

> 你好，需要加工四个零件：
> 1. 三个铝板异形件（P01、P02、P04，激光切割，6061-T6，DXF 已附）
>    - P01/P02 是 4mm 板，P04 是 5mm 板（三件都是 6061-T6，可一起下料）
>    - P01 两个 ⌀10 孔、P02 上端一个 ⌀5 孔、P04 一个 ⌀5 孔——这些**激光切完都要二次绞孔到 H7 公差**（激光精度不够）
> 2. 一个 45# 碳钢车削件（P03，⌀30×12mm，中心 ⌀2.5 通孔，攻 M3 全通螺纹，车完喷透明防锈漆薄层）
>
> 关键尺寸用红色标出（孔心距 ±0.1），是核心物理参数不能跑偏，请用钻模或一次装夹加工。
>
> 表面要求：所有铝件两面 240# 砂纸打磨（哑光，反光会干扰视觉测量），所有棱倒角 C0.5×45°，孔口去毛刺。
>
> 钢件目标质量 66±2g（验收时要称重）。

---

## B. 外购件（淘宝/五金店）

### B.1 框架结构

| # | 名称 | 规格 | 数量 | 单价 | 小计 | 备注 |
|---|---|---|---|---|---|---|
| 1 | 2020 工业铝型材 | 600mm（立柱） | 2 段 | 15 元/段 | 30 元 | 淘宝整段切短到 600，告知卖家 |
| 2 | 2020 工业铝型材 | 500mm（横梁） | 2 段 | 12 元/段 | 24 元 | 同上 |
| 3 | 2020 内置 L 形角连接件 | 配 M5 螺栓 | 4 个 | 5 元/个 | 20 元 | 含 M5 螺栓和 T 型螺母 |
| 4 | M5 内六角螺栓 + T 型螺母 | M5×10 | 8 套（备） | 10 元/套 | 10 元 | 一般角件套装会送，不送再补 |

**B.1 小计**：84 元

### B.2 摆动轴系

| # | 名称 | 规格 | 数量 | 单价 | 小计 | 备注 |
|---|---|---|---|---|---|---|
| 5 | MR105ZZ 微型轴承 | 内 5×外 10×厚 4 mm | 4 个 | 5 元/个 | 20 元 | 详 `轴承.md`；2 装机 + 1 备 + 1 练手 |
| 6a | P06 主轴销 | ⌀5×15 m6 不锈钢圆柱销 GB/T 119.1 | 2 根 | 2 元/根 | 4 元 | 详 `轴销.md`；1 装机 + 1 备 |
| 6b | P05 关节轴销 | ⌀5×12 m6 不锈钢圆柱销 | 2 根 | 1.5 元/根 | 3 元 | 同上 |
| 7 | E 型挡圈 | E5（适用 ⌀5 轴）GB/T 896 规格 5 | 一片（含 20+） | 3 元/片 | 3 元 | 4 处装机用，剩下当备件；按"E5"或"GB/T 896 规格 5"下单 |
| 8 | 钟表润滑油 | 瑞士 MOEBIUS 9020 或类似 | 1 瓶 | 20 元 | 20 元 | 轴承脱脂处理用；一滴/轴 |
| 9 | Loctite 638 轴承固持胶 | 50 ml | 1 瓶 | 25 元 | 25 元 | 轴承外圈过盈胶固持，弥补 H7 孔间隙；评审 1 号建议 |

**B.2 小计**：75 元

### B.3 配重连接

| # | 名称 | 规格 | 数量 | 单价 | 小计 | 备注 |
|---|---|---|---|---|---|---|
| 10 | M3×16 不锈钢内六角螺栓 | DIN 912 | 5 个（备） | 1 元/个 | 5 元 | 连接 P02 摆臂 2 与 P03 钢盘；4mm P02 + 1.5mm 垫片 + 10.5mm 钢丝牙啮合 = 16mm（钢盘 12mm 通孔丝牙，留 1.5mm 不戳穿底面）|
| 11 | M3 平垫 + 弹垫 | DIN 125/127 | 10 个 | 0.3 元/个 | 3 元 | 防松 |

**B.3 小计**：8 元

### B.4 视觉测量

| # | 名称 | 规格 | 数量 | 单价 | 小计 | 备注 |
|---|---|---|---|---|---|---|
| 11 | 哑光黑亚克力板 | 3mm 厚，350×500mm | 1 块 | 30 元 | 30 元 | 视觉追踪用强反差背板 |
| 12 | 3M 反光荧光红圆点 | ⌀5mm 不干胶 | 一片（多） | 15 元 | 15 元 | 视觉追踪标记点，淘宝搜"圆点贴纸" |
| 13 | 棋盘格标定板 | 9×7 角点，格 20mm | 1 张 | 5 元 | 5 元 | 打印 A4 贴硬卡，或买现成铝板款 |
| 14 | 10W LED 平板灯 | 5500K，含调光 | 2 个 | 40 元/个 | 80 元 | 双侧补光，看着像摄影常用的那种 |
| 15 | 灯架 / 桌面三脚架 | 高度可调 | 2 个 | 25 元/个 | 50 元 | LED 灯支撑 |

**B.4 小计**：180 元

### B.5 释放装置

| # | 名称 | 规格 | 数量 | 单价 | 小计 | 备注 |
|---|---|---|---|---|---|---|
| 16 | 电磁吸盘 | 12V，吸力 5-10N，⌀25 | 1 个 | 30 元 | 30 元 | 断电触发 t=0；v2: P03 改 45# 钢有铁磁，吸盘直接吸钢盘，无需软铁片 |
| 17 | 12V 直流电源 + 按钮开关 | 普通适配器 + 自锁开关 | 1 套 | 25 元 | 25 元 | 控制电磁吸盘 |
| 18 | 透明亚克力量角器 | 半圆，180°，⌀100 | 2 个 | 8 元/个 | 16 元 | 读 θ₁ θ₂ 初始角，2 个可校准 |

**B.5 小计**：71 元（v2: 删 16b 软铁片省 5 元）

> **实际装置说明（2026-06）**：电磁吸盘（第 16/17 项，约 55 元）因吸力不足以稳定吸持钢配重，最终未采用，改为手动释放。这不影响结果——每段真实轨迹的初始状态由视频追踪反演得到，不依赖释放机构的标称角度（详见论文 §4.2）。故实际装置 B.5 仅保留量角器作粗参考，释放部分可省约 55 元。

### B.6 设备（如果没有）

| # | 名称 | 规格 | 数量 | 单价 | 小计 | 备注 |
|---|---|---|---|---|---|---|
| 19 | 手机三脚架 | 1.5m 高，含手机夹 | 1 个 | 80-150 元 | 100 元 | 你大概率已经有 |
| 20 | 手机（120fps 慢动作） | iPhone/小米/华为 都行 | 1 部 | 自带 | 0 | iPhone 8 以上、小米 9 以上都支持 |

---

## C. 工具（八成你都有）

- 内六角扳手套装（含 M3、M5）
- 螺丝刀
- 卡尺（数显的最好，0.01mm 精度）
- 小电钻（万一加工厂没把孔倒角好，自己补刀）
- M3 丝攻 + 攻丝扳手（如果加工厂攻丝没做好可以自己补）
- 砂纸 240# 一张（修整毛刺）
- 水平尺（装框架时校准垂直）

---

## D. 总预算汇总

| 类别 | 小计 |
|---|---|
| A 加工件（4 件，P03 改 45# 钢后回落） | 158-235 元 |
| B.1 框架结构 | 84 元 |
| B.2 摆动轴系（含 P05/P06 轴销 + 钟表油 + Loctite 638） | 75 元 |
| B.3 配重连接 | 8 元 |
| B.4 视觉测量 | 180 元 |
| B.5 释放装置（v2: 删软铁片） | 71 元 |
| B.6 设备（按你已有手机/三脚架算 0） | 0-100 元 |
| **总计** | **完整版 576-753 元 / 节省版 305-435 元**（v2: P03 改钢省 ~17 元）|

**预算实控建议**：380-450 元 hits sweet spot。能省的地方：
- B.4 第 14 项 LED 用家里的台灯顶替（损失补光均匀性，但能凑合）
- B.5 第 16/17 项电磁释放本研究最终未采用，直接手动放手即可（初始状态由视频反演、不依赖释放精度），省约 55 元
- B.6 三脚架用书堆顶替（损失重复性，不推荐）

**别省的地方**：
- A 段加工件（精度上去了 AI 才能学到正确动力学）
- B.2 第 5 项轴承（坏轴承 = 实验失败）
- B.4 第 11 项黑亚克力板（视觉追踪精度的命根子）

---

## E. 采购路径

### 一站式（最省事）

淘宝搜下面这些店铺类型，基本一家能搞定 80% 的件：

- "工业铝型材厂家"：B.1 所有件
- "微型轴承"：B.2 所有件
- "亚克力定制"：B.4 第 11 项 + B.5 第 18 项
- "激光切割代加工"：A 所有加工件（直接发 DXF）

### 分散采购（更便宜，但耗时）

- 铝型材：本地建材市场
- 轴承：本地轴承城
- 紧固件：本地五金店
- LED + 三脚架：摄影器材店
- 45# 钢车削：本地小机加工厂（车床活儿，激光厂可能不做）

### 估算到货时间

- 加工件：3-7 天（关键路径）
- 标准件：2-3 天
- 总到齐时间：约 1 周

---

## F. 验收清单

到货后逐项确认：

- [ ] P01 摆臂 1：孔心距实测 250±0.1 mm（卡尺量）
- [ ] P02 摆臂 2：孔心距实测 200±0.1 mm
- [ ] P03 钢盘：实际称重 66±2 g（电子秤量），表面有薄层防锈漆
- [ ] MR105ZZ 轴承：手转应顺滑无卡顿，加 1 滴油后再次检验
- [ ] 2020 型材：切口垂直，端面无毛刺
- [ ] 哑光黑亚克力板：表面无划痕、刮痕

通过验收后下一步进入装配（详见 `~/ChaoticNet/diagrams/02_mechanical_front_view.svg`）。

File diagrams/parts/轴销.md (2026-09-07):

# 轴销规格 P05 / P06

两根标准 ⌀5 圆柱销（不需要定做加工，但要指定精度+长度+数量，**否则采购错了等于白做**）。

---

## P06 主轴销（Pivot Shaft）

**用途**：把 P04 主轴座和 P01 摆臂 1 的主轴承（顶端）连起来，使摆臂 1 能绕它自由旋转。

| 参数 | 要求 |
|---|---|
| 标准 | GB/T 119.2-2000 内螺纹圆柱销（或 GB/T 119.1 普通圆柱销） |
| 公称直径 | ⌀5 |
| 公差等级 | **m6**（+0.012/+0.004，GB/T 119.1 普通圆柱销标准）→ 配 H7 孔成过渡偏过盈 H7/m6 |
| 材料 | 1Cr17Ni7（不锈钢，又叫 304-J3）或 GCr15 轴承钢淬硬 |
| 长度 | **15mm**（v2: 评审建议 25→15，去除多余悬空）|
| 端面 | 两端 C0.5×45° 倒角 |
| 表面粗糙度 | Ra 0.4 以下 |
| 数量 | 2（一根装机，一根备件） |

**长度分解**（按摆臂 4mm 厚 + Loctite 638 装配）：
- 5mm 压入 P04（板厚 5mm）
- 0.5mm 空气间隙 P04↔P01
- 4mm 穿 MR105ZZ 轴承（嵌入 P01 ⌀10 H7 孔）
- 2mm E5 挡圈位 + 倒角空间
- 3.5mm 安全余量（含 2mm 端面倒角）
- 合计 = 15mm

**淘宝搜索**：`圆柱销 5×15 m6 不锈钢` 或 `精密销 ⌀5 15mm 304`，约 2 元/根。

---

## P05 关节轴销（Joint Shaft）

**用途**：把 P02 摆臂 2 顶端和 P01 摆臂 1 下端关节轴承连起来。

| 参数 | 要求 |
|---|---|
| 标准 | 同 P06，普通圆柱销 GB/T 119.1 |
| 公称直径 | ⌀5 |
| 公差等级 | **m6**（+0.012/+0.004，GB/T 119.1 普通圆柱销标准）→ 配 H7 孔成过渡偏过盈 H7/m6 |
| 材料 | 1Cr17Ni7 不锈钢 |
| 长度 | **12mm**（v2: 评审建议 18→12，去除多余悬空）|
| 端面 | 两端 C0.5×45° 倒角 |
| 表面粗糙度 | Ra 0.4 以下 |
| 数量 | 2（一根装机，一根备件） |

**长度分解**（按摆臂 4mm 厚）：
- 4mm 压入 P02（板厚 4mm，全板深度过盈）
- 0.5mm 空气间隙 P02↔P01
- 4mm 穿 MR105ZZ 关节轴承（嵌入 P01 下端 ⌀10 H7 孔）
- 2mm E5 挡圈位 + 倒角
- 1.5mm 安全余量
- 合计 = 12mm

**淘宝搜索**：`圆柱销 5×12 m6 不锈钢`，约 1.5 元/根。

如果 12mm 不好买，**14-15mm 可代替**，多出来那点不影响功能，E5 挡圈位置略外移即可。

---

## 配套用挡圈（必须一起买）

| 名称 | 标准 | 规格 | 数量 | 单价 |
|---|---|---|---|---|
| E 型挡圈 | GB/T 896 | E5（适用于 ⌀5 轴） | 8 个 | 0.3 元/个 |

每根轴的外伸端 1 个挡圈防摆臂滑脱。装机用 2 个（P06 主轴销 1 + P05 关节销 1），备 6 个。

**淘宝搜索**：`E5 挡圈 GB896 不锈钢`，3 元一片（含 20+ 个）。

---

## 装配时的关键检查

### 1. 压入前清洁

⌀5 销和 ⌀5 H7 孔都用 95% 酒精擦一遍，去掉油污+灰尘，否则压入后定位精度受影响。

### 2. 压入方向

销有标记的一面朝**外**（用户能看到的方向），平整面朝向板内。

### 3. 压入工具

- 优选：小型台钳 + 软爪保护
- 次选：橡皮锤 + 木块敲击
- 禁用：直接用铁锤敲

### 4. 压入深度验证

压完用卡尺量外伸量：

| 销 | 板厚 | 应外伸 |
|---|---|---|
| P06 主轴销 | 5mm（P04 板厚） | 10 mm |
| P05 关节销 | 4mm（P02 摆臂厚 v2） | 8 mm（如买 14-15mm 版则 10-11mm）|

少 1-2mm 还能用，少 3mm 以上得拔出来重压。

### 5. 同心度检查

把摆臂插上去后，用手转一圈，应该感觉到**摆臂在轴承上是自由的，没有卡顿/异响**。如果卡，可能是：
- 销略弯了（敲偏了），需要换新销
- 孔不正（P04 二次绞孔有偏差），需要 P04 重做

---

## 不要踩的坑

### 坑 1：买成 h6 公差（之前我自己踩过这个坑——已修正）

h6 是"清光"级（公差全在负侧），配 H7 孔是**间隙配合**——销在孔里能动，根本不固定。**只买 m6**。GB/T 119.1 普通圆柱销默认就是 m6，特意去要 h6 反而买到非标。

### 坑 2：买成不锈钢但强度不够

普通不锈钢圆柱销（A2/304）够用，但如果买的是"装饰销"（A1 级，强度低），长期摆动会被磨损。认准 **m6 + 1Cr17Ni7 标准件**。

### 坑 3：长度差 5mm 就将就

长度差 5mm 时，要么 E 挡圈卡不到位（摆臂会脱），要么压得太深没法用 E 挡圈。多花 2 块钱买对长度的，不要将就。

### 坑 4：忘了买备件

实验过程中销可能被踩弯/磕变形/丢失。**4 根都买**（每个规格各 2，加上备用各 1）才稳。

---

## 总成本

- P06 主轴销 ⌀5×15 m6 × 2 = 4 元
- P05 关节销 ⌀5×12 m6 × 2 = 3 元
- E5 挡圈 × 8（含备件） = 3 元
- **合计：10 元左右**

比起整个项目动辄几百元，这点钱省不得。

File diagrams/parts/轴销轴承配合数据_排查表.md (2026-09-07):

# 轴销 ↔ 轴承 配合数据排查表

**现象**：轴销插不进 MR105ZZ 轴承内孔。
**结论**：不是装错，是公差冲突——m6 销对轴承内圈是**过盈配合**，手插不进是正常的。

---

## 1. 三个配合界面的尺寸数据

| 部件 | 公称 | 公差带 | 实际尺寸范围 | 数据来源 |
|---|---|---|---|---|
| 轴销 P06 / P05 | ⌀5 | m6（+0.012 / +0.004） | **5.004 – 5.012 mm** | 轴销.md |
| 轴承 MR105ZZ 内孔 | ⌀5 | P0 标准磨削（0 / −0.008） | **4.992 – 5.000 mm** | 轴承.md（P0/ABEC-1） |
| 座板 P04 / 摆臂 P02 销孔 | ⌀5 | H7（+0.012 / 0） | 5.000 – 5.012 mm | 组装书.md |
| 摆臂 P01 装轴承孔 | ⌀10 | H7（+0.015 / 0） | 10.000 – 10.015 mm | 轴承.md §5 |

---

## 2. 配合性质计算

| 配合界面 | 配合 | 量值 | 性质 | 该不该手插 |
|---|---|---|---|---|
| **销 ↔ 轴承内孔** | m6 / 轴承孔 | 过盈 **4 – 20 μm** | 过盈 | ❌ 插不进是对的 |
| 销 ↔ P04/P02 板孔 | H7 / m6 | 过渡偏过盈 | 压配合 | 本就要台钳压入 |
| 轴承外圈 ↔ P01 ⌀10 孔 | H7 / 轴承外径 | 过盈压入 | 压配合 | 台钳压，不能敲内圈 |

销永远比轴承孔粗 4 到 20 微米，所以无论怎么对都插不进。组装书 §7.2 里"间隙配合 5-10μm 旷量"那句与 m6 规格矛盾，以本表为准。

---

## 3. 为什么会冲突（设计原因）

同一根销要干两件事：
- 在 P04/P02 板孔里要**固定不动**（需要紧）；
- 穿过轴承内圈要能**装得进去**（需要松或胶固）。

单一直径的销没法同时满足。正确做法：销固定靠 **Loctite 638 厌氧胶**（剪切强度 28 N/mm²，本项目载荷 < 5 N，余量极大），机械过盈交给胶，销本身对轴承内圈做**滑配/微间隙**即可。

---

## 4. 解决方案（按优先级）

### 方案 A · 立刻能干（推荐，省时省钱）
把销**穿轴承的那一段**磨细到滑配：
1. 电钻夹住销尾，低速转。
2. 2000 目砂纸 + 一点机油，轻贴销身那一段抛磨。
3. 卡尺边量边试，目标 **4.990 – 4.996 mm**（比轴承孔小 4–10 μm，手推能滑入、不旷）。
4. 磨完酒精擦净铁屑，再装。
> 销在 P04 里靠 Loctite 638 固定，磨细不影响牢固。

### 方案 B · 重新采购
穿轴承的销改 **h6（0/−0.008）或 g6（−0.004/−0.012）**，与轴承孔成间隙配合，开箱即插。淘宝搜 `圆柱销 5×15 h6 不锈钢`。约 2 元/根，到货要等。

### 方案 C · 绝对禁止
❌ 用锤子 / 台钳把销**硬压过轴承内圈**。力全压在滚珠上 → 压痕（brinelling）→ 衰减时间 τ 报废 → 整个轴承废掉。这是项目命根子，碰不得。

---

## 5. 装好后验证

- 手拨轴承外圈，靠惯性应能**转 2-3 秒**为合格。
- 抬 P01 到水平放手，单摆应自由摆动 **15 秒以上**（脱脂合格的快速预估）。
- 转不动 = 压太紧 / 销还偏粗 / 没脱脂，回查。

---

## 6. 一眼速记

| 想记住的一句话 |
|---|
| 销 5.004–5.012，轴承孔 4.992–5.000，销比孔粗，必须磨细到约 4.99 才滑得进 |
| 销的固定靠胶（Loctite 638），不靠轴承段过盈 |
| 永远不要把销硬压/硬敲过轴承——会压坏滚珠 |

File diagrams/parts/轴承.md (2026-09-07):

# 轴承技术规格（BOM 第 5 项详细要求）

## 为什么轴承是这个项目的命根子

混沌动力学只有在**摩擦远小于惯性力**的窗口内才能干净呈现。轴承摩擦越大，自由摆动衰减越快，留给 AI 学习的"纯混沌"数据就越少。

关键指标：**自由摆动衰减时间常数 τ**——给摆 1 一个 30° 初角放开，让它自由摆动，振幅衰减到一半所需时间。

| τ | 数据可用窗口 | 评价 |
|---|---|---|
| < 10s | < 5s | 失败，混沌还没充分发展就被摩擦吃光 |
| 15-25s | 10-15s | 勉强够 RC 训练，但泛化弱 |
| **30-40s** | **20-25s** | **目标区间** |
| > 50s | > 30s | 超目标，留出充足"看不到底"的混沌轨迹 |

要打到 30-40s τ，轴承不能瞎买。

---

## 推荐规格（按性能从低到高三档）

### 档 1：经济款（约 5 元/个，需要自己处理）

| 参数 | 要求 |
|---|---|
| 型号 | MR105ZZ |
| 尺寸 | 内径 5 × 外径 10 × 厚度 4 mm |
| 材料 | 铬钢 GCr15（不要碳钢，不要不锈钢的不锈轴承） |
| 精度等级 | P0（ABEC-1，标准级） |
| 内部游隙 | C0（标准游隙） |
| 密封 | ZZ（金属防尘盖，**不要 RS 橡胶密封**——拖动太大） |
| 保持架 | **钢保持架**（不要尼龙，低速下尼龙摩擦更大） |

**问题**：出厂带工业重润滑脂，τ 实测 5-8s。**必须自己脱脂+轻油**才能用（流程见下文 § 4）。

淘宝搜：`MR105ZZ 微型轴承 铬钢 ZZ 钢保持架`

### 档 2：高精度款（约 15-25 元/个，开箱可用）

同 MR105ZZ 尺寸，但提级到：

| 参数 | 要求 |
|---|---|
| 精度等级 | **P5（ABEC-5）**——径向跳动 < 4μm |
| 内部游隙 | C2（比 C0 更紧，减少摆臂晃动） |
| 润滑 | **微量低温脂** 或 **干态出厂**（关键升级） |
| 品牌 | NSK / NTN / SKF / NMB（任一日系/欧美） |

τ 实测 25-35s 开箱即用，不脱脂也凑合，脱脂后 40s+。

淘宝搜：`NSK MR105ZZ P5 C2` 或 `MR105ZZ P5 高精度 微量脂`

### 档 3：宝石轴承（约 80-150 元/个，性能天花板）

不用 MR105ZZ 了，用机械手表那种红宝石轴承（synthetic ruby pivot bearings）：
- 内径 5mm 配同样的 ⌀5 光轴
- 摩擦系数比滚珠轴承低 1-2 个数量级
- τ 可达 90s+

适合：项目预算宽裕、想拿"超目标"实验数据冲奖。

淘宝搜：`钟表 红宝石轴承 5mm` 或上 Aliexpress 找 jewel bearings。

---

## 选哪档？

**默认建议：买档 1（4 个，5 元/个 = 20 元）+ 在家做脱脂处理**。

理由：
- 一来 20 元做的事情花 60 元买档 2 也能做，但实验本身就是工程练习——脱脂是给评委讲故事的素材
- 二来档 2 国内现货少，可能等货
- 三来档 1 处理坏了或装配磕了，2 备件随时换

只有时间紧（< 1 周）或动手能力弱才买档 2 开箱即用。

---

## 4. 脱脂 + 轻油处理流程（档 1 必做）

### 4.1 工具

- 95% 工业酒精 或 工业汽油 100ml（淘宝几块钱）
- 小玻璃瓶（医用青霉素瓶最好，能密封）
- 镊子 / 棉签
- 钟表油（淘宝搜"瑞士 MOEBIUS 9020"，约 20 元一瓶，省着用能用几年）
- 干净的擦镜布 / 无尘纸

### 4.2 步骤

1. **拆防尘盖**：MR105ZZ 的金属盖是卡进去的，用细针/手术刀尖**只在一边**沿外圈轻撬一下取下。**只拆一边**——另一边盖留着挡灰。
2. **泡酒精/汽油**：轴承泡进溶剂 5 分钟。期间用手指转动几次，让溶剂冲掉里面的脂。
3. **第二次清洗**：换新溶剂再泡 5 分钟，转动几次。
4. **自然晾干**：放镊子上等溶剂全部挥发（10-20 分钟）。
5. **手感验证**：晾干后用手指夹住内圈，外圈应该**靠惯性能转 3-5 秒**（之前带脂时大概 0.5 秒就停了）。
6. **加一滴油**：钟表油滴一滴在内圈和外圈之间的滚珠位置。**绝对不要多加**——多一滴 τ 立刻少 10s。
7. **再次手感验证**：加油后转动应该仍然顺滑，可能比纯干态稍慢但相差不多。
8. **盖回防尘盖**：金属盖卡回去，按压贴合。

### 4.3 常见错误

- **加油过多**：第一次新手通病。试试看用注射器针头**蘸一下**就够了。
- **没干透就加油**：酒精残留 + 油 = 乳化 = 摩擦增大
- **盖没卡好**：装上后晃晃听有没有响。响 = 盖松了 = 灰进去 = 几天后 τ 暴跌

---

## 5. 安装到摆臂的要点

⌀10 H7 孔 + 轴承外径 ⌀10（公差一般 ±0.005），是**过盈压入**（压配合）。

### 5.1 正确做法

- 用台钳 + 软爪（铜板/铝板）慢慢压
- 或者用橡皮锤轻轻敲（敲外圈，**绝对不能敲内圈**——损伤滚珠）
- 压入深度：轴承外端面与摆臂端面平齐

### 5.2 检查

压入后用手指拨内圈，应该**靠惯性能转 2-3 秒**。如果转不动 = 压入过紧或孔变形了。

---

## 6. 验收 τ 测试（这是项目第一个真实"实验"）

### 6.1 实验条件（必须严格写进论文，不能含糊）

**配置**：**单摆**（只装 P01 摆臂 1 + 主轴承，**不装 P02/P03**）
理由：测的是单个轴承摩擦贡献。装了关节，下摆耦合进来，就是双摆混沌不是衰减测量了。

**初始条件**：
- 释放角 θ₁(0) ≈ 30°（**手动干净放手即可**——衰减常数 τ 由振幅包络的指数拟合得到，与释放角的微小误差、初始小扰动无关，所以不需要电磁吸盘那类精确释放机构；唯一要求是别主动推、别带初速度）
- 角速度 θ̇₁(0) ≈ 0（静止放手）
- 环境温度 25 ± 2 °C（钟表油 25 °C 黏度 100 cSt，温度变 10 °C 黏度变约 40%，直接影响摩擦）
- 环境湿度无要求（轴承封闭）
- 测试在装配 + Loctite 638 固化 24 小时后进行

**采集**：手机 60 fps 即可（衰减很慢，60fps 绰绰有余；120fps 慢动作也行），相机布置见 `03_camera_setup_top_view.svg`，整段录像 30-60 秒甚至更长，直到基本停下。

### 6.2 数据处理（衰减常数 τ 的严格定义）

不能凭"几个周期到一半"目测，要拟合：

1. 视觉追踪 P₁ 标记点的轨迹，提取角位移序列 θ₁(t)
2. 找出每个**峰值**（局部极大）的角度 θₚₑₐₖ(i)，记下时间 tᵢ
3. 取**振幅包络**：A(tᵢ) = θₚₑₐₖ(i)
4. 拟合指数模型：A(t) = A₀ · e^(-t/τ)
   - **τ 就是这个指数衰减常数**
   - 在 t = τ 时，振幅降到 A₀/e ≈ 36.8%
5. 用最小二乘法拟合，要求 R² ≥ 0.98 才接受

**对照"半衰期"语境**：若题外说 "T₁/₂"，关系是 τ = T₁/₂ / ln(2) ≈ 1.443 · T₁/₂。

### 6.3 重复次数与统计

- **测 5 次** 独立释放（每次释放后等摆完全停下再下一次）
- 取 5 次 τ 的均值 ± 标准差，写论文用 τ̄ ± σ 形式
- 若 σ / τ̄ > 10% → 实验流程有问题，找原因（释放不稳？环境温度波动？）

### 6.4 验收标准

- **τ̄ ≥ 30 s, σ ≤ 3 s** → 合格，进装配
- 20 ≤ τ̄ < 30 s → 临界，重做脱脂 + 减少加油量
- τ̄ < 20 s 或 σ > 5 s → 不合格，换轴承（备件用上）或买档 2

### 6.5 论文里怎么写

第 3 章 3.1.2 节示范：

> 轴承采用 MR105ZZ 微型铬钢深沟球轴承（10×5×4 mm）。出厂润滑脂经 95% 工业酒精脱脂后，单滴瑞士 MOEBIUS 9020 钟表油重新润滑。装配采用 Loctite 638 厌氧固持胶（24 h 固化）。
>
> 摩擦特性验证：取约 30° 初始角手动静止释放的单摆配置，60 fps 视频追踪 P₁ 标记点，对振幅包络做指数拟合 A(t) = A₀e^(-t/τ)。5 次独立测量得 **τ̄ = (XX.X ± X.X) s** (R² > 0.98)，对应有效混沌窗口 (Window) ≈ 0.7τ ≈ XX s，满足后续 RC 训练对数据时长的要求。
>
> 环境温度 25 ± 2 °C。

把 XX 填实测值即可。**这种写法评委挑不出毛病，因为条件、方法、统计都披露了**。

---

## 7. 备用轴承用途

第 5 项 BOM 4 个轴承：
- 装机用 2 个（摆 1 顶端 + 摆 1 末端关节）
- 备件 1 个：装机过程压坏一个怎么办
- **测试样本 1 个**：脱脂前先在它身上练手，搞砸了不影响装机的那 2 个

---

## 8. 总成本对比表

| 方案 | 轴承费 | 钟表油 | 工时 | 预期 τ | 数据质量 |
|---|---|---|---|---|---|
| 档 1 不脱脂 | 20 元 | 0 | 0 | 5-8 s | ❌ 项目废 |
| **档 1 + 脱脂处理** | 20 元 | 20 元 | 1 小时 | 30-40 s | ✅ **推荐** |
| 档 2 直接用 | 80 元 | 0 | 0 | 25-35 s | ✓ 可用 |
| 档 2 + 脱脂 | 80 元 | 20 元 | 1 小时 | 40-50 s | ✓✓ 优秀 |
| 档 3 红宝石 | 320 元 | 0 | 装机难 | 90 s+ | ✓✓✓ 天花板 |

---

## 9. 如果加工厂能配的话

如果你认识的加工厂还做装配，可以问问：

> "能不能压入轴承一起做？我提供 4 个 MR105ZZ，你帮我压进 ⌀10 H7 孔里，1 个孔 1 个轴承。"

这能省你台钳 + 铜板软爪那一套工具。多加工费一般 5-10 元/孔，总共 20-40 元，看个人需要。

不过自己压入也是项目体验的一部分，不算坏事。

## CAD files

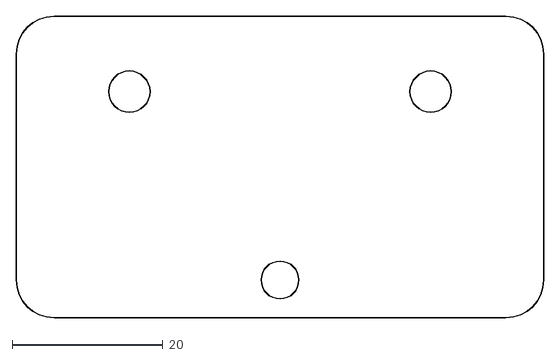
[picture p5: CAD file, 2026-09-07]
diagrams/parts/dxf/P04_pivot_bracket.dxf
70.0 x 40.0

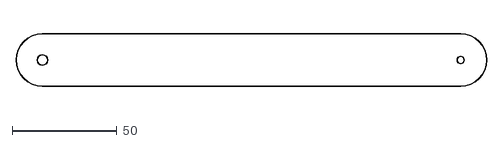
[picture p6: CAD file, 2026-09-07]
diagrams/parts/dxf/P02_arm_2.dxf
225.0 x 25.0

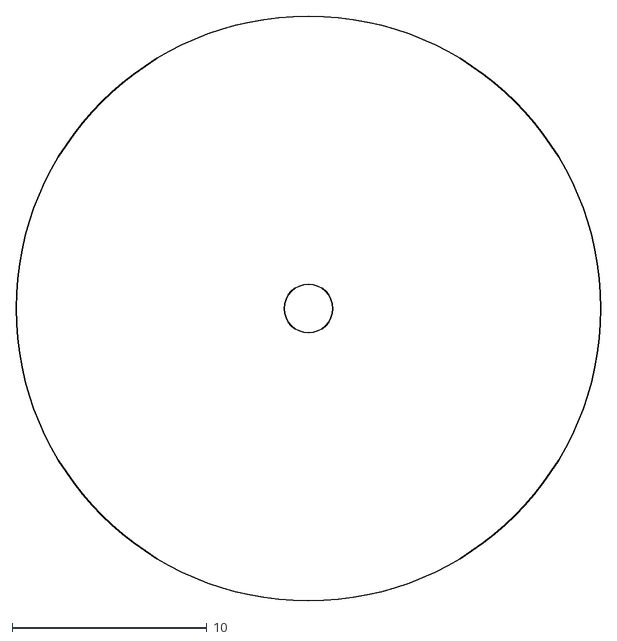
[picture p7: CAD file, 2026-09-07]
diagrams/parts/dxf/P03_brass_weight.dxf
30.0 x 30.0

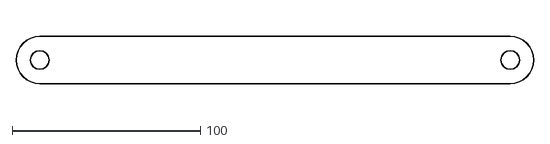
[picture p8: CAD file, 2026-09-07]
diagrams/parts/dxf/P01_arm_1.dxf
275.0 x 25.0

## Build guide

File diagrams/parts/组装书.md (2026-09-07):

# ChaoticNet 双摆装置 装配手册
**版本**：v1（2026-06-11）
**配套文件**：`BOM.md`、`轴承.md`、`轴销.md`、`P01-P04*.svg`、`04_frame_assembly.svg`
**预计耗时**：3 小时实操 + 48 小时 Loctite 固化等待

---

## 0. 开工之前（5 分钟必读）

### 0.1 安全 + 心态

- 这不是宜家家具，是物理实验装置。**精度 ≠ 蛮力**——拧螺丝靠手感，不靠力气
- 全程戴白棉手套（裸手汗渍会污染轴承）
- Loctite 638 沾皮肤马上用酒精擦掉
- 安排两天：**第一天搭框架+预装轴承**，**第二天等 Loctite 固化完再总装**

### 0.2 工具清单（开工前自查）

- [ ] 内六角扳手套装（含 M3、M5）
- [ ] 一字 + 十字螺丝刀小号
- [ ] 数显卡尺（0.01mm 精度）
- [ ] 小型台钳 + 软铜爪（压入轴承用）
- [ ] 橡皮锤（敲销用，**别用铁锤**）
- [ ] 95% 工业酒精 + 棉签 + 无尘纸
- [ ] 注射器针头（点 Loctite + 钟表油用，2-3 元一包）
- [ ] 镊子（拿 E 挡圈）
- [ ] 水平尺（10cm 小号即可）
- [ ] 电子秤（0.1g 精度，验收 P03 配重用）
- [ ] 手机 / 相机（记录每一步，出问题好回溯）

### 0.3 工作台环境

- 桌面光滑、有边沿——E5 挡圈一掉就找不着，桌沿挡一下
- 顶光别太亮——轴承内部要观察反光，强光会反而看不清
- 准备 4 个浅盘子分类放小零件：①轴承 ②销 ③挡圈 ④紧固件

---

## 1. 来料验收（30 分钟，对照 BOM.md § F）

按 BOM 验收清单逐项打勾。**重点复核**：

| 项 | 关键尺寸 | 工具 | 判定 |
|---|---|---|---|
| P01 摆臂 1 | 两 ⌀10 孔心距 250±0.1 mm | 卡尺 | 不达标退回 |
| P02 摆臂 2 | ⌀5 孔与 M3 孔心距 200±0.1 mm | 卡尺 | 不达标退回 |
| P03 钢盘 | 质量 66±2 g | 电子秤 | 偏差大调下料 |
| P04 主轴座 | 轴孔距顶 35±0.1 mm | 卡尺 | 不达标退回 |
| MR105ZZ 轴承 | 手转顺滑无卡顿 | 手感 | 卡顿挑出来 |
| P05/P06 销 | 端面无毛刺、销直 | 目检+尺 | 弯销退回 |

**任何加工件不达标都不要将就**——是后续 τ 测试不通过的源头。

---

## 2. 第一天上午：搭框架（45 分钟）

### 2.1 立柱 + 横梁组立

参考 `04_frame_assembly.svg`。

1. 把 2 段 600mm 立柱、2 段 500mm 横梁、4 个 L 形角连接件铺在桌面
2. **认方向**：立柱的 T 槽朝**内侧**（指向摆运动平面），横梁的 T 槽朝**前侧**（摄像头方向）
3. 上横梁先和 2 立柱用 4 个角件初步连上，但**所有 M5 螺栓先半紧**（手指拧得动那种），等下要校方
4. 下横梁同上

### 2.2 校方（关键，决定整机水平）

1. 把方框立起来放桌面（开口朝下，作"门"形）
2. 拿水平尺贴上横梁——气泡偏 → 拧底部 4 个角件的螺栓微调
3. 角尺贴立柱和横梁的内角——量两条对角线（X 形交叉）：**两对角线差 < 1mm** 才算方
4. 方框对了，**逐个把 M5 螺栓紧到位**（力矩 5 N·m 左右，内六角扳手拧到手感"嘎"一下即可）

### 2.3 验收
- [ ] 立柱垂直度 ±0.5°（水平尺验）
- [ ] 对角线差 < 1mm
- [ ] 整框无晃动（手摇上横梁不弹）

---

## 3. 第一天下午：轴承脱脂处理（1 小时实操 + 静置）

**这一步是 τ ≥ 30s 的决定性环节**。详细流程见 `轴承.md § 4`，这里给操作摘要：

1. 准备：4 个 MR105ZZ + 100ml 工业酒精 + 玻璃瓶 + 钟表油
2. **只在 1 面** 用细针撬下金属盖（另一面留挡灰）
3. 浸酒精 5 分钟 + 转动几次冲走脂
4. 换酒精再浸 5 分钟
5. 镊子捏住晾 15 分钟（必须**干透**才能加油）
6. 手感验证：手指夹内圈，外圈惯性转 3-5 秒为合格
7. **注射器针头蘸一下** 钟表油，点 1 滴在内外圈之间（**绝对别多**）
8. 盖回防尘盖

**做完做记号**：4 个轴承都贴个小标签写"已脱脂"，避免和原装的搞混。

---

## 4. 第一天下午：摆 1 子组件预装（30 分钟 + Loctite 固化 24h）

### 4.1 P01 + 2 个轴承（这一步必须做完才能下班，固化要 24h）

1. 拿 1 个白色塑料布铺桌面（Loctite 滴到塑料上不毁桌子）
2. 棉签蘸酒精把 P01 的 2 个 ⌀10 H7 孔内壁擦一遍
3. 同样擦 2 个轴承的外圆
4. **少量** Loctite 638 涂孔壁（针头蘸一下沿孔内圈描一圈即可，**别涂轴承上**）
5. **用台钳软爪压入**轴承——压到轴承端面与 P01 板面齐平
   - 板厚 4mm，轴承 4mm → 完全嵌入，两面与板齐平（理想状态）
6. 多余的 Loctite 立即用棉签擦掉（固化前能擦掉，固化后只能机械刮）
7. 2 个孔都装完后，P01 平放在塑料布上**水平静置 24 小时**——这个时间不能省

### 4.2 验收（24h 后做）
- [ ] 轴承外圈不能用手拔下（用蛮力试试看，不动 = OK）
- [ ] 内圈手拨能轻松自由转
- [ ] 无明显 Loctite 残胶外溢

---

## 5. 第一天下午：摆 2 子组件预装（30 分钟 + 24h 固化）

跟 § 4 同步做。

### 5.1 P02 + P05 销 + 关节轴承 1 个

1. 擦干净 P02 顶端 ⌀5 H7 孔和 P05 销
2. 少量 Loctite 638 描孔壁
3. 台钳压入 P05 销（⌀5×12 m6）—— 板内 4mm（全板深度） + 外伸 8mm 给关节轴承用
4. **静置 24h**

### 5.2 P02 + P03 钢盘（不用 Loctite，可现做现拆）

1. P02 末端 ⌀3.4 过孔穿 M3×16 螺栓（v2.1: 4mm P02 + 1.5mm 垫片 + 10.5mm 钢丝牙啮合 = 16mm；钢盘 12mm 通孔丝牙，留 1.5mm 不戳穿底面）
2. 螺栓尾穿 M3 平垫 + 弹垫
3. **P03 钢盘的 M3 螺纹接住**，拧紧（力矩 1.5 N·m，手感"咯"一下停手）
4. 这一步现在装不装都行，可推迟到第二天

---

## 6. 第二天上午：P04 主轴座装上横梁（20 分钟）

### 6.1 高度计算
- 上横梁内底面距地 = 立柱长 - 下横梁占用厚度 = 约 580mm
- P04 板面与横梁底面贴合
- 摆 1 主轴心距上横梁底面 = 35mm（P04 设计值）
- 摆 1 长度 250mm + 关节 + 摆 2 长度 200mm + P03 半径 15mm = 总伸展 465mm
- 摆 2 完全直下时距下横梁顶面 = 580 - 465 = 115mm（**留有余量，安全**）

### 6.2 安装
1. 准备 2 个 T 形螺母塞进上横梁底部 T 槽
2. 滑到中心位置（左右两侧距离立柱各 250mm 处）
3. P04 板面贴上横梁底面，M5 内六角螺栓穿 P04 的 2 个 ⌀5.5 过孔
4. 拧 T 螺母 —— **先半紧**，留余量调正位
5. 卡尺量 P04 板面距上横梁端面，两侧等距 = 中心居正
6. 拧紧 M5（力矩 5 N·m）

### 6.3 验收
- [ ] P04 板面垂直摆动平面（不晃）
- [ ] 轴孔 S 中心距离上横梁底面 35mm（卡尺验）
- [ ] 用力推 P04 应纹丝不动

---

## 7. 第二天上午：P06 销 + 摆 1 挂上（15 分钟）

### 7.1 P06 销压入 P04
1. 擦干净 P06 销（⌀5×15 m6）和 P04 的 ⌀5 H7 轴孔
2. 少量 Loctite 638 描孔壁
3. 软爪台钳把 P06 销压入 P04 —— **压入深度 5mm**（外伸 10mm）
4. 卡尺量外伸量，应为 10±0.5mm
5. **静置 1 小时** 让 Loctite 凝固到能承受手动操作（24h 才完全固化，但 1h 可继续装配）

### 7.2 P01 套上 P06 销
1. 摆 1 顶端轴承内圈对准 P06 销
2. 滑入 —— 轴承应该**轻松自由滑入**（销 m6 + 轴承内圈 H8，间隙配合，会有 5-10μm 旷量是正常的）
3. 套到底（贴 P04 板面，但**留 0.5mm 间隙**别压死，否则摩擦增大）
4. **E5 挡圈** 用镊子从外侧卡入销末端的卡槽（卡进去会"啪"一声）
5. 拨动 P01 — 应自由摆动

### 7.3 验收（关键一步）
- [ ] 抬 P01 让它指向水平（90° 偏），轻轻放手
- [ ] P01 应自由摆动 **15 秒以上**（这是单摆配置的快速预估，正式 τ 测要详细流程见 § 11）

如果 5 秒内停 → 出问题了，常见原因：
- 轴承没脱脂干净
- P01 撞到了什么 / 摩擦框架
- E 挡圈卡得太紧贴住板面
- P06 销压偏了

---

## 8. 第二天上午：关节装配（10 分钟）

### 8.1 P01 下端轴承 + P02 上端的 P05 销

把摆 2 子组件（P02+P05 销，已固化 24h 的）拎过来：

1. P01 下端的轴承内圈对准 P05 销
2. 滑入到底（板面贴近但留 0.5mm 间隙）
3. E5 挡圈装上（**反方向** ——卡在 P05 销的 P02 那一侧外端，不是 P01 这一侧）

### 8.2 验收
- [ ] P02 应能绕关节自由摆动
- [ ] 抬 P02 让 P01 保持垂直、P02 水平，放手 → P02 应自然下垂回中并摆动

---

## 9. 第二天上午：钢配重 + 系统级测试（30 分钟）

### 9.1 P03 装到 P02 末端
（若 § 5.2 已经做，跳过；否则现在做）

1. 螺栓穿 P02 末端 ⌀3.4 孔
2. 拧入 P03 的 M3 螺纹（**少量 Loctite 222 螺纹胶**——比 638 轻一档，防松不死锁）
3. 力矩 1.5 N·m，**水平校验**：P03 圆盘平面应垂直摆运动平面

### 9.2 系统级首测（看混沌）
1. 摆 1 拉到 60° 偏右（拿手扶住）
2. 摆 2 拉到水平甩到右侧（也手扶）
3. **同时放手**
4. 应看到"混乱、不可预测、看着就头晕"的混沌摆动 —— 看 10 秒就足够确认装配成功

如果看着像规则摆动（周期性、可预测）→ 摩擦太大或者关节卡，回 § 7-8 复查。

---

## 10. 第二天下午：视觉测量系统（45 分钟）

参考 `02_mechanical_front_view.svg` 和 `03_camera_setup_top_view.svg`。

### 10.1 哑光黑亚克力背板
- 立在装置后方距摆运动平面 50mm（不能贴太近，留摆运动空间；不能太远，距离透视会让摆变形）
- 用胶带粘到框架立柱上，**整面无反光**

### 10.2 反光红圆点（追踪标记）
- 圆点 ⌀5mm，贴在：
  - **P₁ 位置**：P01 下端轴承中心（关节处）
  - **P₂ 位置**：P02 末端的 P03 钢盘中心
- 贴的时候用棉签压实，避免脱胶
- **额外贴 1 个参考点**：贴在 P04 不动的板面上，作图像稳像基准

### 10.3 棋盘格标定板
- 贴在装置左侧立柱外侧，距摄像头方向 ~10mm 朝前
- 9×7 角点，格 20mm 已知标定板
- 用于后续相机内参标定（OpenCV calibrateCamera 用）

### 10.4 LED 平板灯 ×2
- 双侧 45° 入射，距摆 0.8-1m
- 5500K 白光，调到中等亮度（避免溢光让反光圆点饱和）
- 灯具不能在镜头画面里

### 10.5 手机 + 三脚架
- 三脚架放在装置正前方 1.2-1.5m
- 手机横屏，距地高度对准摆 1 中心点
- 设置 **60fps 录像模式**，分辨率 1080p（与 29 段数据集一致；衰减/τ 测试同此设置）
- 录制时关闭自动对焦——手动锁焦在摆面

### 10.6 验收
- [ ] 试录 5 秒，回看：圆点清晰可见，背景纯黑
- [ ] 摆运动全程在画面内（拉到最大 60° 也不出框）
- [ ] 标定板四角清晰可见

---

## 11. 第二天下午：初值释放（手动，5 分钟）

> 原计划用电磁吸盘做精确释放，但 45# 钢配重偏重、吸盘吸力不足以稳定吸持，实测吸不住，已弃用。改为手动释放——这不影响数据质量：每段轨迹的初始状态 (θ₁,θ₂,ω₁,ω₂) 都是后期从视频反演出来的，不依赖释放角的标称值（详见论文 §4.2）。

### 11.1 怎么释放
- 把摆 1、摆 2 抬到想要的大致角度（背板上若印了量角器可作粗参考，不必精确）
- **干净放手**：别推、别甩，让它从静止自然落下
- 开头留 1–2 秒静止再放手，方便后期定位起始帧
- 想要初值多样，每段换一个不同角度放

### 11.2 验收
- [ ] 放手时不带明显横向推力 / 甩动
- [ ] 开头有 1–2 秒静止段

---

## 12. 第二天下午：τ 验收测试（关键，1 小时）

### 12.1 配置切换到单摆
- **拆掉** P02 + P05 销 + P03（这一组件保留好，做完 τ 测试再装回）
- 只留 P01 挂在 P04 上

### 12.2 测试流程（详细见 `轴承.md § 6`）
1. 把单摆抬到约 30°，手动干净放手（别推、别带初速度——τ 由振幅包络指数拟合得到，与释放角小误差无关）
2. 60fps 录像，录到几乎停（30-60 秒甚至更长）
3. 视觉追踪 P₁ 标记点提取 θ₁(t)
4. 找出每个周期的峰值 θ_peak(t_i)
5. 拟合 A(t) = A₀·e^(-t/τ)，**要求 R² ≥ 0.98**
6. **重复 5 次** 取均值 τ̄ ± σ

### 12.3 判定
- τ̄ ≥ 30s, σ ≤ 3s → ✅ 合格，进入正式数据采集
- 20 ≤ τ̄ < 30s → ⚠️ 临界，重做脱脂 + 减少油量
- τ̄ < 20s → ❌ 不合格，换轴承（备件用上）

### 12.4 装回双摆
τ 合格后，把 P02 + P03 装回。可以开始正式采集混沌数据了。

---

## 13. 常见故障速查

| 症状 | 可能原因 | 检查/解决 |
|---|---|---|
| 摆 1 不能自由摆 | 轴承摩擦大 | 拆下来重新脱脂；或换备件轴承 |
| 摆 1 摆几下歪一边 | P06 销压偏 / P04 没装正 | 拆 E 挡圈，取下 P01 复查 P04 板面水平度 |
| 关节卡 | P05 销压入 P02 不正 | 取下 P05 重新压入；严重时 P02 重做 |
| τ < 20s | 油加多了 / 没脱脂干净 | 拆下重做脱脂，油量再减半 |
| 录像 P₁ 追踪丢失 | 圆点脱胶 / 灯光不均 | 重贴圆点；调灯位 |
| 摆 1 一甩飞了 | E5 挡圈忘装 / 装反 | 重装挡圈 |
| 框架晃 | M5 没拧紧 / T 螺母滑了 | 紧固后再校方 |
| 不混沌（周期性） | 关节卡 / 配重太小 / 配重位置不对 | 复查 §7-§9 |

---

## 14. 完工 checklist

全部装完后逐项打勾：

- [ ] 框架方正、不晃
- [ ] P04 高度正、贴合横梁
- [ ] P01 自由摆动（单摆配置 τ ≥ 30s 验收通过后勾选）
- [ ] 关节自由旋转
- [ ] P03 牢固、平整
- [ ] 反光圆点已贴 P₁ / P₂ / 基准点
- [ ] 棋盘格标定板已固定
- [ ] LED 灯定位、亮度适中
- [ ] 手机 60fps 录制就绪
- [ ] 手动放手手法练熟（干净、不带初速度）
- [ ] 量角器（若贴）读数清晰，仅作粗参考

---

## 附录 A：力矩速查

| 部位 | 螺栓 | 力矩 | 加 Loctite？ |
|---|---|---|---|
| 框架 4 角件 | M5×10 | 5 N·m | 否 |
| P04 上横梁 | M5×10 | 5 N·m | 否 |
| P03 上 P02 | M3×16 | 1.5 N·m | 是（222 轻锁） |
| 轴承入 P01 | -（过盈） | -（手压） | 是（638 强锁） |
| P06 销入 P04 | -（过盈） | -（手压） | 是（638 强锁） |
| P05 销入 P02 | -（过盈） | -（手压） | 是（638 强锁） |

---

## 附录 B：Loctite 用量参考

每个孔涂量"针头蘸 1 下"，约 0.02ml。一瓶 50ml Loctite 638 够装 2000+ 个孔——剩下的密封好可以用几年。

固化时间（25°C）：
- 1 小时：可手动操作
- 6 小时：60% 强度
- 24 小时：100% 强度
- **强度 28 N/mm² 剪切**——本项目所有载荷小于 5N，倍数足够

---

## 附录 C：照片记录建议

每个关键步骤都拍一张存档，文件命名 `step_X.Y_描述.jpg`，按编号存到 `~/ChaoticNet/assembly_photos/`。
出问题时回看比凭记忆找原因快 10 倍。

---

**下一步**：装配完成后，进入数据采集 → RC 训练 → 论文撰写流程。详见 `~/ChaoticNet/README.md`（暂未生成，等后续）。

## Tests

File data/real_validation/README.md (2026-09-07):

# data/real_validation/ — 单片旧口径（非论文头条）

本目录的 `summary.csv` 是**单段**（tracked_1392.csv）的旧式对比
（ESN 0.308 / PINN 0.283 / Hybrid 0.283 s），由 `rc/real_validation.py` 生成，
只用于单片详图与叠加视频，**不是真实零样本头条**。

真实零样本头条口径 = **29 段多 run 中位**：
ESN 0.167 / PINN 0.417 / Hybrid 0.450 s（物理 ≈ **2.7×** ESN）。
权威来源：`data/canon_multirun/summary.csv` 与 `data/canonical_results_B.md`。
多段管线脚本：`rc/real_validation_multi.py`。

注：本目录 `figures/`（含 29 段真实战绩墙 PNG）仍在被论文/演示引用，勿删。

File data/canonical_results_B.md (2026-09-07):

# 混沌之眼 B(分布质量) canonical 结果 —— 论文唯一数字来源（2026-06-19）

口径：每个模型独立训练 N 次（ESN 换 reservoir seed×10；PINN/Hybrid 非确定性重训×8），
每 run 取"该 run 自己混沌 trial(horizon<9.9s) 的中位视界"（真实侧取 29 片中位），
报 per-run 中位的 **median [IQR]**。数据 data/canon_multirun/summary.csv。τ_L=0.762s（实测中位，sim/lyapunov.py）。

## 仿真内（median [IQR] over runs；/τL 用 τL=0.762）

> **2026-09-08 修正**：ESN 行已换成闭环起跑点修正后的值（旧值 0.40 / 0.53 τL，倍数 2.2/3.8/7.0）。
> 根因见 data/esn_closedloop_fix/：旧闭环入口把训练末帧输入喂了两遍，预测窗第 0 帧即带约 1.9° 偏差。
> 逐位等价关系 legacy(x0,u0,n) == readout_first(step(x0,u0),u0,n) 已验证 maxdiff=0。
> **真实侧调用属正确族，真实表四个数字一个不动。**

| 模型 | 中位 (s) | IQR | /τL | ×ESN |
|---|---|---|---|---|
| ESN（数据驱动基线，修正后） | 0.70 | [0.55, 0.70] | 0.91 | 1.0 |
| PINN（λ=0.1，物理损失） | 0.88 | [0.77, 1.03] | 1.15 | 1.3× |
| 纯数据 MLP（λ=0，消融） | 1.55 | [1.31, 1.68] | 2.03 | 2.2× |
| Hybrid（解析先验+残差） | 2.85 | [2.12, 3.27] | 3.74 | 4.1× |

注：修正后 ESN 落在文献报告的"约 1–2 个 Lyapunov 时间"储池计算基线区间内（0.91 τL），
说明基线未被削弱；own_chaos 口径下 ESN 变强会使更多 trial 被判为非混沌而剔出其自身子集，
故 0.70 s 偏保守、可视为下界（详见 data/esn_closedloop_fix/summary.md 的交集口径对照）。

## 真实零样本迁移（median [IQR] over runs，29 片）

| 模型 | 中位 (s) | IQR | ×ESN |
|---|---|---|---|
| ESN | 0.167 | [0.167, 0.179] | 1.0 |
| 纯数据 MLP（λ=0） | 0.358 | [0.333, 0.404] | 2.15× |
| PINN（λ=0.1） | 0.417 | [0.367, 0.438] | 2.50× |
| Hybrid | 0.450 | [0.450, 0.467] | 2.70× |

物理损失真实增益 PINN(λ0.1)/MLP(λ0) = 0.417/0.358 = **1.16×**。

## 关键诚实结论

1. 真实头条保住：物理先验模型真实迁移约 ESN 的 2.5–2.7×（旧论文 2.8×，现可复现）。
2. 物理损失是"迁移正则"，非"仿真内拟合工具"：仿真内它略降准（λ0.1 0.88 < 纯数据 1.55），
   但真实迁移它涨 16%。仿真内纯数据/Hybrid 打头阵；真实靠物理结构。
3. sim→real 主因是仿真保真度（分布质量匹配真硬件）+ 物理结构；Hybrid 最强。
4. λ-sweep（data/lambda_sweep）：真实 λ0=0.317 → λ0.1=0.425 见顶；λ 太大(=1)仿真内被拖累。故选 λ=0.1。

## τ_L（分布质量实测，sim/lyapunov.py → data/lyapunov.csv）
λ_max 中位 1.31/s → τ_L 中位 0.762s；均值 λ 1.21/s → τ_L 0.827s。（点质量旧值 0.81s。）

## 四方固定子集交叉验证（per-trial 跨 run 中位，data/fair_compare/four_way_horizons.csv）
三方混沌 N=32（**旧 ESN 路径**）：ESN 0.294 / PINN 0.506(1.72×) / 纯数据 0.881(3.0×) / Hybrid 2.167(7.38×)。

> **2026-09-08 修正**：按修正后的 ESN 路径重算（data/esn_closedloop_fix/fourway_fixed_subset.csv）：
> 同一子集(legacy 定义, N=32) ESN 0.733 → PINN 0.51×0.69 / 纯数据 0.88×1.20 / Hybrid 2.17×2.95；
> 按修正路径重新判定混沌子集(N=28)：ESN 0.558 / PINN 0.429(0.77×) / 纯数据 0.765(1.37×) / Hybrid 1.794(3.21×)。
> **注意方向变化**：在这个逐 trial 口径下 PINN 低于修正后的 ESN（0.69–0.77×），与 per-run own_chaos 口径的 1.3× 不同号。
> 这与论文主线并不冲突——论文本就主张"物理损失在仿真内无益甚至有代价，价值只在 sim→real 迁移下显现"——
> 但答辩若被问到仿真内 PINN 是否真的强于 ESN，应如实回答"口径相关、优势很小"，不要说成稳健领先。
> 论文正文未引用四方逐 trial 数字，故本次无须改论文；此处留档供答辩备查。
结论方向与 per-run 一致（PINN>ESN、Hybrid 最强、纯数据仿真内>物理PINN）。

## 三天花板误差分解（§7.3，分布质量，29 片，4s 窗，PINN）
口径：rc/error_decomposition.py，模型为分布质量 canonical（data/pinn|hybrid/model.pt），
解析积分器用分布质量 baseline.py / baseline_damped.py（阻尼 b=1.66e-5、c=8.72e-6，06-18 拟合）。
- h_real（PINN）= 0.42s（与 §7 真实表 0.417 一致）；Hybrid 0.48s。
- C_dampmis（纯阻尼失配天花板，完美初值）= 1.35s（h_real 的 3.2×）。
- C_chaos（纯初值不确定天花板，完美模型，每片实测 δω）= 1.90s（h_real 的 4.6×）。
- 初值不确定度：σθ 中位 0.45°，δω 中位 0.09 rad/s。
- 距混沌天花板可改进空间 = 1.90 − 0.42 ≈ 1.5s。
- h_damp 佐证（带阻尼模型重测真实）：Hybrid 0.93× 基本不变、PINN 0.68× 反降 → 4s 短窗"修阻尼"无收益。
图 data/real_validation/figures/error_decomposition.png（已用分布质量模型重生成）。

## 阻尼场景侧实验（§8 限制，分布质量，单次训练）
data/sim_damped 已用分布质量 baseline_damped 重生成；pinn/hybrid_damped 重训。
in-sim-damped 混沌 N=33：PINN 中位 4.98s、Hybrid 中位 3.96s（逐 trial 配对差异小且受随机性影响）。
→ 二者视界相当、Hybrid 解析先验无明显优势 → PINN 端到端学到未建模阻尼。论文以 PINN≈5.0/Hybrid≈4.0 量级表述。

## 点质量 vs 分布质量真实迁移对照（支撑选 B；data/epoch_transfer/distmass_transfer.csv）
PINN 真实中位：点质量 λ0=0.267 / λ1=0.275（约 0.27s）；分布质量 λ0=0.375 / λ1=0.400。
→ 点质量迁移明显更差，分布质量是真实头条成立的前提。论文 §7 写"点质量约 0.27s"。

## 备份与可复现
点质量 canonical 快照 data/_pointmass_canonical_backup_20260619/；冻结表 data/_frozen_backup_20260619/；
论文点质量版 archived/paper_点质量旧版/main_点质量_20260619.tex（原 paper/main.tex.pointmass_bak，已于 06-21 git mv 归档）。
脚本：tools/canon_multirun_distmass.py（主）、tools/lambda_sweep_distmass.py、sim/lyapunov.py。

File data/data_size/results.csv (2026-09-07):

n_train_trials | seed | n_samples | full_median | chaos_median | n_chaos
2 | 42 | 4796 | 0.24166666666666667 | 0.24166666666666667 | 50
2 | 7 | 4796 | 0.3208333333333333 | 0.3208333333333333 | 50
2 | 13 | 4796 | 0.3583333333333333 | 0.3583333333333333 | 50
5 | 42 | 11990 | 0.4916666666666667 | 0.4916666666666667 | 50
5 | 7 | 11990 | 1.05 | 1.05 | 50
5 | 13 | 11990 | 0.5541666666666667 | 0.5541666666666667 | 50
10 | 42 | 23980 | 2.0625 | 1.9041666666666668 | 48
10 | 7 | 23980 | 2.4625000000000004 | 2.45 | 49
10 | 13 | 23980 | 1.475 | 1.475 | 50
20 | 42 | 47960 | 2.166666666666667 | 1.9541666666666666 | 48
20 | 7 | 47960 | 2.425 | 1.925 | 41
20 | 13 | 47960 | 3.220833333333333 | 3.095833333333333 | 46
50 | 42 | 119900 | 5.1125 | 3.2916666666666665 | 39
50 | 7 | 119900 | 5.3916666666666675 | 2.7958333333333334 | 34
50 | 13 | 119900 | 6.0625 | 2.9749999999999996 | 36

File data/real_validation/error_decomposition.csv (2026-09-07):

tag | rel_deg | fps | sigth_deg | dw_self | h_real_PINN | h_real_Hybrid | h_damp_PINN | h_damp_Hybrid | h_model_PINN | h_model_Hybrid | C_dampmis | C_chaos_self | C_chaos_0.05 | C_chaos_0.1 | C_chaos_0.15 | C_chaos_0.2 | C_chaos_0.3
1430 | 101.3 | 60.0 | 0.704 | 0.138 | 0.350145540824812 | 0.26677755491414246 | 0.26677755491414246 | 0.26677755491414246 | 1.0671102196565698 | 0.8170062619245613 | 1.4172557604813818 | 1.1838253999315071 | 1.900790078763265 | 1.4172557604813818 | 0.8503534562888291 | 0.8170062619245613 | 0.6002494985568205
1431 | 87.1 | 60.0 | 0.587 | 0.114 | 0.45018923789908527 | 0.5335576152878048 | 0.21675778121067069 | 0.7002943700652438 | 0.500210264332317 | 0.7669890719762193 | 0.7002943700652438 | 1.167157283442073 | 1.167157283442073 | 1.8674516535073167 | 0.7669890719762193 | 0.7336417210207316 | 0.23343145668841458
1432 | 111.2 | 60.0 | 0.742 | 0.151 | 0.1500630702102299 | 0.1500630702102299 | 0.1500630702102299 | 0.1500630702102299 | 0.3001261404204598 | 1.1504835382784293 | 1.1504835382784293 | 0.5502312574375097 | 2.1509040063466287 | 1.4005886552954792 | 0.5335575829697063 | 0.5002102340340997 | 0.40016818722727976
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

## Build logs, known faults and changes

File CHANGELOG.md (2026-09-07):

# ChaoticNet 变更日志

## v3.1 · 2026-09-04（答辩交付物成套 + 论文竞赛格式改版 19→32 页 + 仓库口径清扫）

汇总 v3.0（2026-06-21 凌晨）之后的全部工作。数字口径未变，仍以 `data/canonical_results_B.md`
为唯一真相源；`tools/paper_audit.py` 6/6 全绿。

### 已入库提交（2026-06-21 深夜 – 06-23）

- 真实录像零样本预测：新增 `tools/overlay_real_prediction.py`（实拍视频上叠加模型预测）与
  `tools/embed_demo_into_pptx.py`（把叠加视频嵌成答辩 deck 的演示页）。
- 答辩交互演示：新增 `tools/live_demo.py`——评委现场输初始角度，看 ESN / PINN / Hybrid 三摆赛跑。
  随后 6 轮体验迭代：脱靶后保身份色可辨 + 重置守卫 + 播放速度滑块；解耦视觉刷新与播放速度
  （全速度段稳定 60fps）；仿真 fps 退回 60 修 ESN 闭环锁死并加锁死诚实标记；角度/角速度滑块旁
  加精确输入框 + 三摆常驻预览；进度条 / 暂停 / 可拖动擦洗；配套 `tools/demo_doctor.py` 一键自检。
- 第三、四轮多智能体审计：修复答辩 PPT 消融页残留的点质量旧值、归档点质量旧 tex；
  严谨性补强 + 可复现性收口 + 许可与清理。
- 口径清扫：入口文档统一到 v3 分布质量口径、收紧唯一真相源；旁支文件残留的旧值同步到 v3，杜绝误读。
- 答辩 PPT：嵌入蝴蝶效应开场动画 + 29 段真实战绩墙、修下标字形，另出「完整演示版」deck。
- 目录治理：散落根目录的文档统一归入 `文档/`（答辩 / 操作手册 / 报告与计划）；
  清理 06-13 废稿素材、早期骨架、截图产物，`build_slides` 旧生成器归档。

### 工作区改动（07–09 月，本条目发布时随同提交）

- **论文 19 页 → 32 页**（`paper/main.pdf`）。主要是竞赛格式规范改版 + 内容补充：
  正文改小四 12pt、行距≈24 磅；新增目录页；参考文献改 GB/T 7714—2015 顺序编码制
  （正文引用改右上标，样式文件随项目放在 `paper/texstyles/gb7714/`，编译需带 `TEXINPUTS`）；
  cleveref 交叉引用中文化（节/图/表/式/算法/附录）；图表标题小一号加粗；页眉去除、页码居中；
  新增「讨论与展望 · 应用前景」小节；新增双摆物理模型示意图 `fig_pendulum_schematic.png`。
- **文献 17 → 24 条**（`paper/references.bib`），新增分布质量摆、物理约束学习综述、PINN 电力应用、
  DeLaN、GraphCast、盘古气象、物理储池计算；正文 24 处引用与 bib 条目一一对应。
- **论文插图统一重制**：`three_way_compare` 改 2+1 版式（原三联横排压得难读）并标注 N=32 混沌子集口径；
  误差分解、多视界-角度、能量扫描、PINN 训练 loss、实拍叠加图的字号与正文协调、dpi 提高、
  改 `bbox_inches="tight"`；`diagrams/01_physics_model.svg` 同步更新。
- `tools/paper_audit.py` 检查 B 支持 tex 中显式写出的相对路径插图（如 `../data/...`）。
- `paper/编译说明.md` 补 `TEXINPUTS` 与 GB/T 7714 样式说明。
- **新增交付物**：匿名投稿版论文（`paper/main_匿名投稿版.pdf`，32 页）、作品介绍与评委意见修订版 PDF、
  A3 深蓝高清海报（`poster/`、`混沌之眼_A3海报_深蓝高清修订版.pptx`）、命题类蓝色样式答辩 PPT，
  以及多轮 PPT 图表放大 / 投影可读性 QC 产物（`ppt_*_2026081x/`、`.ppt_workflow_qc/`、`video_restore_20260815/`）。
- **新增脚本**：`tools/render_pendulum_schematic.py`、`tools/report_figure_qc.py`、
  `tools/fig_butterfly_distmass_large.py`、`tools/fig_error_decomposition_large.py`、
  `tools/fig_real_horizon_large.py`、`tools/make_errdec_slide.py`、
  `tools/build_pptx_blue_competition_style.py`、`sim/plot_insim_canon_4model.py`、
  `sim/replot_pinn_loss.py`、`tracking/replot_qc_1448.py`。
- **新增文档**（`文档/`）：人工智能使用声明、成员贡献说明、实验仪器说明文档、
  论文审校报告_2026-07-14、截稿冲刺计划书_2026-09-04。
- **口径加固**：`tools/bootstrap_sim.py` / `bootstrap_real.py` 的置信区间改用分布质量数据源，
  不再读点质量期的 `data/v2_50trial_2026-06-11/horizon_compare_50.csv`（该文件与旧 README 一并
  标注为仅供存档）；点质量期旧权重 `model_pointmass.pt` / `model_oldparams.pt` 移入
  `archived/old_models/`。
- **清理**：删除根目录 Office 崩溃残留的隐藏临时文件 `.~*.pptx`；README 的页数 / 文献数 /
  检查项数 / 文档路径同步为现状。

## v3.0 · 2026-06-21（分布质量迁移 + 真实零样本全管线 + 工程质量五项闭环）

点质量 A → 分布质量 B 的 v3 级跃迁（6/17–6/21 汇总）：

- 物理模型：全套从点质量切到分布质量 B（M1≈96.5g、M2≈139g、质心距/转动惯量由 BOM 反推），data/sim 即 B；点质量底档存 data/_pointmass_canonical_backup_20260619/。
- 真实零样本：29 段实测双摆 sim→real 全管线跑通，零样本迁移（按设计不在真实数据上训练）。真实中位 ESN 0.167s / PINN 0.417s / Hybrid 0.450s。
- 阻尼拟合：sim/fit_damping.py 能量耗散率法从 16 段反推 b≈1.66e-5（粘性）+ c≈8.72e-6（二次空气阻力，占总耗散≈78%），写入 baseline_damped 默认值。
- 单摆 τ 衰减实测：90° 释放重复两次（552.0 / 550.8s），等效 τ≈130s，超标 4×。
- 消融重跑：tab:ablation-lambda 与 tab:ablation-data 用分布质量重跑替换点质量逐数值（新增 tools/lambda_ablation_distmass.py、data/ablation_distmass/）；λ=0 完胜 λ=1 由 1.5× 增至 2.9×，数据量每翻倍约 2×（50 trial 中位 5.52s≈7.3 τ_L）。
- 论文：14 页 → 19 页 PDF，全 TODO 清零，tools/paper_audit.py 6/6 绿；衰减测试节口径对齐 fit_damping，§sim2real 误差分解三天花板（1.35 / 1.90 / 0.42）。
- 答辩 PPT：改用 ppt-master 生成 23 页瑞士极简（分布质量数字），导出 混沌之眼_答辩PPT_瑞士极简.pptx + Word 版；旧 06-13 网页 PPT（ppt-magazine/ ppt-swiss/，点质量旧值）已被取代。
- 工程质量五项闭环：fit_damping 叙述对齐、验收报告口径统一（标定 0.43px / τ≈130s 已入论文）、A/B 决策落地、消融口径统一、git 版本控制初始化。
- 杂项：新增 requirements.txt；参考_早期骨架/ 归档进 archived/；删除过时的 论文τ补丁_粘贴用.txt（论文已可直接编辑，workaround 作废）。

## v2.1.2 · 2026-06-13（答辩 PPT 双风格 + 网页转 pptx 管线）

新增：

- ppt-magazine/ — 杂志风（电子杂志 × 电子墨水，靛蓝瓷主题）网页 PPT，14 页，guizang-ppt-skill 风格 A
- ppt-swiss/ — 瑞士国际主义风（克莱因蓝 IKB）网页 PPT，13 页，风格 B，过 validate-swiss-deck 校验，用 12 种 S 版式
- tools/shoot_slides.mjs — playwright-core + 系统 Chrome 逐页全屏截图（1920×1080@2x），截图前隐藏 #nav/#hint
- tools/build_pptx_from_shots.py — 截图拼成 16:9 全屏图 pptx
- 产物：混沌之眼_答辩PPT_杂志风.pptx（14 页）、混沌之眼_答辩PPT_瑞士风.pptx（13 页）

说明：两版 PPT 共用同一故事线（0.15→0.64s 逼近 0.81s 天花板、3.4×、λ=0 反直觉、全仿真口径诚实），
4 张结果图（three_way / horizon / sensitivity / datasize）都已嵌入。pptx 为整页图片，改文案需回改
ppt-*/index.html 再重跑 shoot + build 脚本。待明天收集他人意见后迭代。

## v2.1.1 · 2026-06-13（τ_L 归一化修正 + audit 加固）

修正：

- sim/plot_three_way.py 的 TAU_L 从遗留的 0.12 改为自测 0.81，与论文 §2 / README 统一。
  之前 three_way_summary.csv 的 tau_L 列（1.25/5.14/5.42）和 three_way_compare.png 的
  τ_L 参考线用的是旧的 0.12 基准，跟论文表 1（0.19/0.79/0.80）打架。
- 重新生成 csv + png，重编论文 PDF 嵌入新图（仍 14 页）。
- tools/paper_audit.py 新增检查 F：核 csv 的 tau_L 列 = 中位/0.81 + 画图脚本常量为 0.81，
  堵上"只核中位秒数、漏核归一化"的洞（这次靠 chaos-status 肉眼发现）。顺手修 docstring 的 \cite SyntaxWarning。

## v2.1 · 2026-06-12（loop 模式上线 + 反直觉发现归档）

新增：

- tools/paper_audit.py — paper / README / csv 一致性监控 loop，5 项检查全自动
- tools/hp_sweep.py — PINN 超参 / 架构 自动 sweep，12 组完整 search 写出 leaderboard
- tools/fair_compare.py — 公平四方对比（ESN/PINN/Hybrid/λ=0 在同 N 同 epoch 同 seed）
- baseline_damped.py 加 --b/--n/--out CLI 参数（实测 τ 后可直接换 b）
- animate_compare.py 加 --trial/--fps/--slow CLI 参数
- tracking/track.py fit_circle 加 try/except 回退

⚠️ 反直觉发现（已归档 data/fair_compare/，paper 未改）：

在干净 baseline 仿真数据 + 同 N=27 同 epoch=300 同 seed=42 公平对比下：

| 模型 | 视界中位 | vs ESN |
|---|---|---|
| ESN | 0.150s | 1.0× |
| PINN（λ=1.0） | 0.617s | 3.38× |
| Hybrid | 0.650s | 3.56× |
| λ=0 纯数据 MLP | 0.758s | 4.88× ← 最高 |

phys loss 在干净仿真数据上不仅没帮助，还略拖后腿（PINN/lam0 = 0.93×）。
解释：baseline 数据本身完美符合 Lagrangian，data loss MSE 给的梯度已足够；phys loss 是冗余约束。
但 PINN/Hybrid 在 noisy 实测数据上仍可能有用（W4 实测后验证）。

**保留发现，paper 主论点暂不改。**等 W4 实测数据出来 + 终稿阶段再 decide：
- 选项 A：加 λ=0 作消融基线进主表，新故事"phys loss 真正价值在实测 OOD 数据"
- 选项 B：λ=0 只放附录 ablation，保留原 3.4× 主论点

### 后续确认（同日深夜）

multi_seed 5 seed × 3 λ 鲁棒性验证（tools/multi_seed.py）：

| Seed | λ=0 | λ=1 |
|---|---|---|
| 42 | 0.838 | 0.508 |
| 7  | 1.425 | 1.229 |
| 13 | 1.425 | 0.738 |
| 21 | 1.038 | 0.538 |
| 100 | 0.592 | 0.538 |

λ=0 在 5/5 个 seed 上视界都 > λ=1，均值 1.063s vs 0.710s（~1.5× 提升）。
→ v2.1 反直觉发现稳健，不是单 seed 巧合。

LNN 实施尝试（rc/lnn.py）：

简化版 LNN（Tanh MLP 128×4 + cosine lr + grad clip）训练 loss 剧烈震荡（两个数量级间跳变），
最终视界中位仅 0.08s。归档为 future work，paper 已加 LNN 实施挑战章节。
Cranmer 原工作使用 LBFGS / 二阶优化器 / deep ensemble，本简化实现不够。

---

## v2.0 · 2026-06-11（晚间冲刺）

19 项产出，全部在一次会话里完成。

### 新增数据 / 模型

- 阻尼仿真 baseline_damped.py（v3 ground truth，b ≈ 1e-4 N·m·s/rad）
- 50 组完整 sweep（ESN + PINN + Hybrid，三套独立 model.pt）
- 阻尼数据上 PINN vs Hybrid 50 组对比
- 初值精度敏感性扫描（±0.1° / 0.5° / 1.0°，每档 K=10）
- 50 组实测 Lyapunov 指数（中位 λ=1.24/s，τ_L=0.81s）

### 新增工具

- rc/hybrid.py 解析-NN 混合模型（Universal Differential Equation 范式）
- rc/sweep_50.py / sweep_damped.py / sensitivity.py
- sim/animate.py / animate_compare.py（三色对比 mp4）
- sim/plot_horizon_50.py / plot_three_way.py / lyapunov.py
- tracking/track.py（OpenCV HSV + 最小二乘圆拟合，0.12° 中位误差）
- tools/smoke.py（项目自检 < 30 秒）
- tools/acceptance.py（W3 装置到货验收：τ / 重复性 / 棋盘格标定）

### 论文（paper/main.tex）

- 从 5 页骨架扩展到 12 页 PDF
- 中文 + 英文双摘要
- 引言文献综述写完（15 篇文献，覆盖双摆 / RC / PINN / SciML / 视觉 / 阻尼）
- 物理模型 M / b 矩阵显式展开 + Lyapunov 自测节
- 实验装置章节填实（含 R5 圆角 P04 等最新硬件设计）
- 视觉系统章节（含 0.12° 跟踪精度验证）
- AI 模型章节（ESN / PINN / Hybrid 三种 + PINN 训练 algorithm 1 伪代码）
- 结果与讨论（基于 50 组真实统计，3.4× 中位提升）
- Appendix：仓库结构 + 一键复现命令 + 超参数表
- 所有红字 [TODO] 清零

### 项目治理

- .gitignore
- 全 Python 模块 sys.path 兼容（无 cwd 依赖）
- v2_50trial_2026-06-11/ 完整快照（数据 + 图 + 权重）

### 核心数字（论文最终主张）

|  | ESN | PINN | Hybrid |
|--|--|--|--|
| 视界 中位（s） | 0.150 | 0.642 | 0.650 |
| 视界 中位 / τ_L | 0.19 | 0.79 | 0.80 |
| 提升 vs ESN | 1× | 3.4× | 3.6× |

τ_L = 0.81s（50 组自测中位值，独立于文献的 0.12s 估计）。

### 下一会话接着干

W3 装置到货后：

1. 跑 tools/acceptance.py（τ 衰减 + 重复性 + 棋盘格）→ 拿到实测 b（阻尼系数）
2. 用实测 b 重跑 sim/baseline_damped.py
3. tracking/track.py 直接对实物视频（可能要调 HSV 阈值给 3M 反光荧光红）
4. 用实测数据替换或对照 50 组 sweep
5. paper 补"实测 vs 仿真"对比章节

W4 起：

- 论文反复修订（导师 + 队员 2 轮 review）
- 视觉系统标定章节实测数据补
- 阻尼系数实物拟合后重训 Hybrid 看是否真显优势

## v1.0 · 2026-06-11（清晨）

- 装置设计冻结（P04 圆角从 R10 改 R5，配重盘从 13mm 改 12mm 加速加工）
- sim/baseline.py 50 组无阻尼仿真
- rc/esn.py + rc/pinn.py 各 5 组 baseline
- paper/main.tex 5 页骨架
- 项目执行计划 14 周 + 5 人分工

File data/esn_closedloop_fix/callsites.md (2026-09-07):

# ESN 闭环 `predict` 调用点影响面清单

生成脚本：`tools/esn_closedloop_fix.py`（本文件由脚本自动写出，勿手改）
生成时间：2026-09-05 01:07:17

## 判据（结构性，与阈值无关）

`rc/esn.py::ESN.predict(x0, u0, n)` 的循环体是「先 `step` 再 `readout`」，
因此它**隐含要求 `x0` 尚未消费过 `u0`**（x0 比 u0 落后一个储池步）。

训练契约（`rc/esn.py:105-129`）：`X[t] = step(X[t-1], U[t])`，
读出特征是 `[X[t], U[t], 1] → U[t+1]`，即状态与**产生它的那一帧输入**配对。

于是判据只有一条：

| 传入 `predict` 的 `(x0, u0)` | 判定 | 后果 |
|---|---|---|
| `x0` **已消费过** `u0`（即 `x0 = X[k]`, `u0 = U[k]`） | **错误族** | 最后一帧输入被喂两遍，预测窗第 0 帧就带误差 |
| `x0` **未消费过** `u0`（即 `x0 = X[k-1]`, `u0 = U[k]`） | **正确族** | 与训练契约一致，第 0 帧对齐 |

已逐位验证的恒等式（`data/esn_closedloop_fix/equivalence_real.txt`，maxdiff = 0.000e+00）：

```
esn.predict(x0, u0, n)  ==  predict_readout_first(esn.step(x0, u0), u0, n)
```

即旧实现 = 修正版「晚起跑一个储池步」。

**反向禁令**：不能把 `predict_readout_first` 同参数裸换进正确族调用。
实测真实侧 29 段同参数裸换 maxdiff = 3.332e+00，
预测窗第 0 帧角度误差中位从 0.132° 暴涨到 7.054°（最大 15.246°）。

## 错误族（6 个调用点，全部在仿真内路径）

修法：`pred = e.predict(x_final, U_tr[-1], n)` → `pred = predict_readout_first(e, x_final, U_tr[-1], n)`
（参数不变，只换函数）。

| # | 文件:行 | 上下文 | 影响的已发布数字 |
|---|---|---|---|
| E1 | `rc/esn.py:194` | `run_one()`：`train(U[:n_train])` → `predict(x_final, U_tr[-1], n_pred)` | 一切仿真内 ESN 的源头；`data/rc/esn_summary.csv` |
| E2 | `tools/esn_seed_variance.py:67` | `horizon_for()`，逐行复刻 E1 | `data/esn_seed/*`；**并被 `canon_multirun_distmass.py:127` 调用** → `data/canon_multirun/{insim_runs,summary}.csv`、`data/fair_compare/four_way_horizons.csv` 的 `esn` 列 |
| E3 | `tools/esn_grid_search.py:155` | `horizons_for_group()`，`x_final = X[-1]`（= `X[n_train-1]`） | `data/esn_grid/` 全部 leaderboard |
| E4 | `tools/esn_grid_search.py:186` | `_audit_unit()`，`e.predict(X[-1], U_tr[-1], n_pred)` | `data/esn_grid/audit_divergence.csv`、`audit_summary.csv` |
| E5 | `tools/threshold_robustness.py:179` | `_insim_curves_esn()`，逐行复刻 E1，返回偏差曲线 | `data/threshold_robustness/` 的**仿真侧 ESN 列**（论文里那个 0.404 及其阈值扫描曲线全部偏低；真实侧不受影响） |
| E6 | `sim/animate_compare.py:71` | 演示动画 `run_esn()` | 只影响 `figures/` 里的对比动画/静帧，无表格数字 |

## 正确族（4 + 2 个调用点，全部在真实侧或滑窗路径）——**不得改动**

共同特征：`train(U[:i0-1], Y[:i0-1])` 后 `predict(x_final, U[i0-1], n)`，
`x_final = X[i0-2]` 尚未消费 `U[i0-1]`。

| # | 文件:行 | 上下文 | 产出的数字 |
|---|---|---|---|
| C1 | `rc/real_validation.py:108` | 单片 IMG_1392 详图版 | `data/real_validation/`（单片图） |
| C2 | `rc/real_validation_multi.py:104` | `run_esn()`，29 段群体统计 | **真实零样本头条 ESN 0.167s** 及 2.15×/2.50×/2.70× 的分母 |
| C3 | `tools/window_mining.py:79` | `run_esn_fixed_lead()`，固定 lead 滑窗 | `data/window_mining/`（分层交叉点） |
| C4 | `tools/live_demo.py:120` | `predict_esn()` 演示 | 无论文数字 |
| C5 | `tools/esn_grid_real.py:240` | 今晚新增（第 4 项）；`x_final = X[-1]` 但 `X` 只跑到 `U[:i0-1]` | `data/esn_grid_real/` |
| C6 | `tools/esn_grid_real.py:395` | 今晚新增（第 4 项）的 sanity check | 同上 |

> C5/C6 属今晚在写的新脚本，按 2026-09-05 00:41 的版本判定为正确族；
> 若该脚本后续改动了训练切片，需重新判定。

## 因此需要在 9/9 全量重算时打包处理的下游产物

1. `data/canon_multirun/{insim_runs.csv, summary.csv}` 的 ESN 仿真内行（经 E2）
2. `data/fair_compare/four_way_horizons.csv` 的 `esn` 列（经 E2，且**只有这一个来源**）
3. `data/esn_seed/{esn_seed_results.csv, esn_seed_summary.csv}`（E2）
4. `data/esn_grid/` 全部（E3/E4）——注意 leaderboard 前列的 `stage2_chaos_q3` 已顶到 10.0 天花板，修正后只会更饱和
5. `data/threshold_robustness/` 的仿真侧 ESN 列（E5）——**真实侧不动**
6. `data/rc/esn_summary.csv` 与 `data/rc/figures/`（E1）
7. 论文：`paper/main.tex:116`、`:148-150`（摘要倍数）、`:526-529`（tab:horizon-compare 的 ESN 行与三个倍数）、
   以及引用四方固定子集 N=32/ESN 0.294/PINN 1.72× 的正文段落
8. `data/canonical_results_B.md` 的「仿真内」表与「四方固定子集交叉验证」段

## 不受影响（可原样保留）

- 真实零样本迁移四个数字 **0.167 / 0.358 / 0.417 / 0.450**（C2，正确族）
- `data/window_mining/` 的分层结论（C3，正确族）
- `data/threshold_robustness/` 的**真实侧**列
- 全部 PINN / Hybrid / MLP 数字（不走 ESN 路径）

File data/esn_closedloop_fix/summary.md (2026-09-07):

# 第 1 项结果：ESN 闭环多消耗一步的修正与影响面

生成时间 2026-09-05 01:07:17；脚本 `tools/esn_closedloop_fix.py`

## 自证门槛

| 门槛 | 内容 | 结果 |
|---|---|---|
| G1-A | `legacy(x_f,u0,n) == readout_first(step(x_f,u0),u0,n)` 逐位相同 | PASS，maxdiff = 0.000e+00 |
| G1-B | 同参数裸换必须**不**等价（反向禁令取证） | PASS，真实侧 maxdiff = 3.332e+00，帧0误差中位 0.132° → 7.054° |
| G2 | legacy per-run own_chaos 中位复现 canon_multirun/summary.csv | 0.4041666666666667 [0.239583, 0.458333]（目标 0.4041666666666667） |
| G3 | legacy 逐 trial 跨 run 中位复现冻结 four_way `esn` 列 | maxdiff = 2.220e-16 |

## 仿真内表（own_chaos 口径，10 seed，可直接替换 tab:horizon-compare 的仿真内块）

| 模型 | 中位 (s) | IQR | /τL | ×ESN(旧) | ×ESN(修正) |
|---|---|---|---|---|---|
| ESN 旧（错误路径） | 0.404 | [0.240, 0.458] | 0.53 | 1.00× | — |
| **ESN 修正** | **0.696** | [0.551, 0.700] | 0.91 | — | 1.00× |
| PINN（λ=0.1）[冻结] | 0.875 | — | 1.15 | 2.16× | **1.26×** |
| 纯数据 MLP（λ=0）[冻结] | 1.550 | — | 2.03 | 3.84× | **2.23×** |
| Hybrid[冻结] | 2.850 | — | 3.74 | 7.05× | **4.10×** |

每 run 混沌子集大小：旧 30–38 条，修正后 25–33 条。

**own_chaos 口径偏保守，必须点破**：ESN 变强后更多 trial 视界 ≥9.9s 被踢出各自的混沌子集，而被踢出的恰恰是修正版表现最好的那些 trial。因此 0.696s 是**下界**。同时给出消除子集漂移的交集口径（只保留两条路径都判为混沌的 trial）：

| 口径 | ESN 旧 | ESN 修正 | 每 run N | PINN/ESN | MLP/ESN | Hybrid/ESN |
|---|---|---|---|---|---|---|
| own_chaos（各自子集） | 0.404 | 0.696 | 30–38 → 25–33 | 2.16× → 1.26× | 3.84× → 2.23× | 7.05× → 4.10× |
| 交集（同一子集） | 0.302 | 0.696 | 25–33 | 2.90× → 1.26× | 5.13× → 2.23× | 9.43× → 4.10× |

> 交集口径的 PINN/MLP/Hybrid 中位仍取冻结的 per-run own_chaos 值（未按交集重算），所以那三个倍数只是量级参考，不能当正式数字引用；正式表用 own_chaos 行。

## 四方固定子集（逐 trial 跨 run 中位；PINN/MLP/Hybrid 复用冻结列）

| 口径 | N(三方) | ESN | PINN | ×ESN | MLP | ×ESN | Hybrid | ×ESN |
|---|---|---|---|---|---|---|---|---|
| legacy(旧/错误) | 32 | 0.294 | 0.506 | 1.72× | 0.881 | 3.00× | 2.167 | 7.38× |
| fixed(修正) | 28 | 0.558 | 0.429 | 0.77× | 0.765 | 1.37× | 1.794 | 3.21× |
| 同一子集(legacy定义) | 32 | 0.294 | 0.506 | 1.72× | 0.881 | 3.00× | 2.167 | 7.38× |
| 同一子集(legacy定义)/ESN_fixed | 32 | 0.733 | 0.506 | 0.69× | 0.881 | 1.20× | 2.167 | 2.95× |

## 真实侧（完全不受影响）

真实零样本 ESN 0.167s / MLP 0.358s / PINN 0.417s / Hybrid 0.450s 四个数字**一个不动**，因为真实侧调用（`rc/real_validation_multi.py:104`）属正确族。见 `callsites.md`。

## 影响面

见同目录 `callsites.md`：错误族 6 个调用点、正确族 6 个（其中 2 个是今晚新增的 `tools/esn_grid_real.py`）。`tools/threshold_robustness.py:179` 的仿真侧 ESN 曲线同样受此影响，其真实侧不受影响。

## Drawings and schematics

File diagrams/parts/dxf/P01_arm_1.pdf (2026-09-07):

P01 · 摆臂 1（Pendulum Arm #1） | 单位 mm · 比例 1:1 · GB/T 1804-m

275 ±0.2

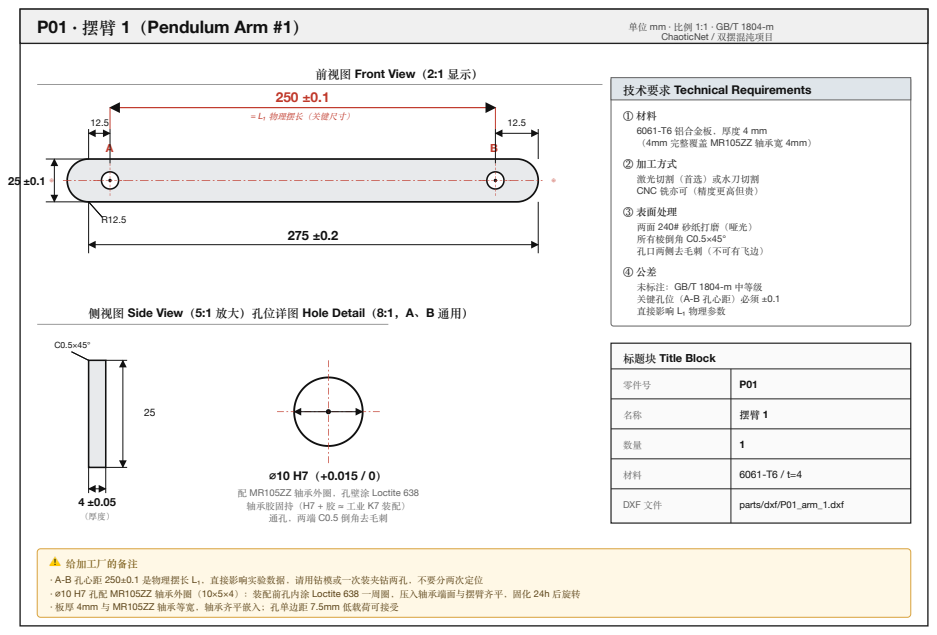
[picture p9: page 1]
ChaoticNet / 双摆混沌项目; 零件号; DXF 文件; parts/dxf/P01_arm_1.dxf

前视图 Front View（2:1 显示）

技术要求 Technical Requirements

= L₁ 物理摆长（关键尺寸）

6061-T6 铝合金板，厚度 4 mm （4mm 完整覆盖 MR105ZZ 轴承宽 4mm）

② 加工方式
激光切割（首选）或水刀切割
CNC 铣亦可（精度更高但贵）
③ 表面处理
两面 240# 砂纸打磨（哑光）
所有棱倒角 C0.5×45° 孔口两侧去毛刺（不可有飞边）

未标注：GB/T 1804-m 中等级
关键孔位（A-B 孔心距）必须 ±0.1 直接影响 L₁ 物理参数

侧视图 Side View（5:1 放大）

孔位详图 Hole Detail（8:1，A、B 通用）

标题块 Title Block

配 MR105ZZ 轴承外圈，孔壁涂 Loctite 638 轴承胶固持（H7 + 胶 ≈ 工业 K7 装配）

通孔，两端 C0.5 倒角去毛刺

⚠️ 给加工厂的备注
· A-B 孔心距 250±0.1 是物理摆长 L₁，直接影响实验数据，请用钻模或一次装夹钻两孔，不要分两次定位
· ⌀10 H7 孔配 MR105ZZ 轴承外圈（10×5×4）：装配前孔内涂 Loctite 638 一周圈，压入轴承端面与摆臂齐平，固化 24h 后旋转
· 板厚 4mm 与 MR105ZZ 轴承等宽，轴承齐平嵌入；孔单边距 7.5mm 低载荷可接受

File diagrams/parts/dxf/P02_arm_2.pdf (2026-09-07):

P02 · 摆臂 2（Pendulum Arm #2，配重端） | 单位 mm · 比例 1:1 · GB/T 1804-m

## 前视图 Front View（2:1 显示）

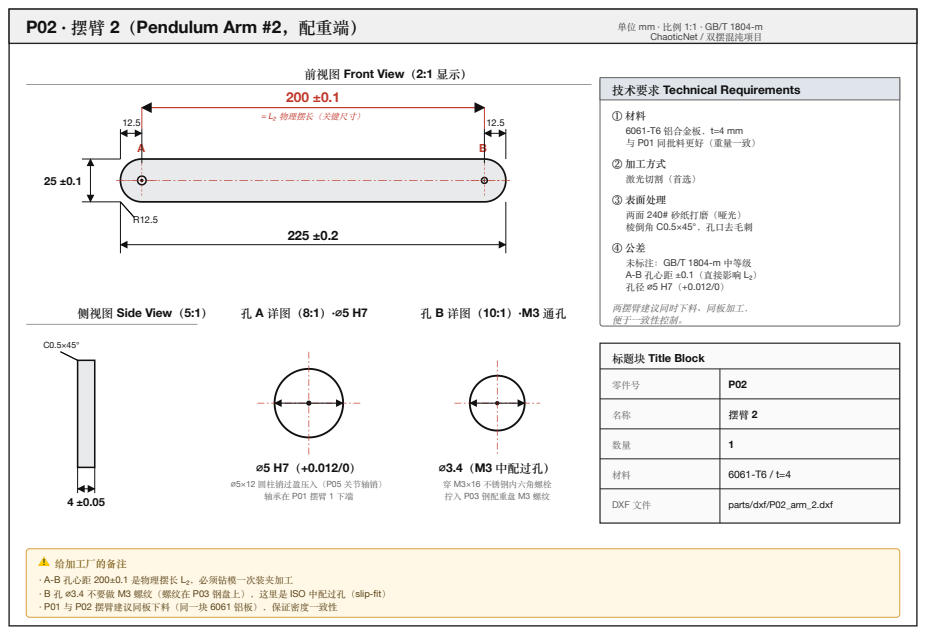
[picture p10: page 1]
ChaoticNet / 双摆混沌项目; ⌀5×12 圆柱销过盈压入（P05 关节轴销）; 零件号; DXF 文件; parts/dxf/P02_arm_2.dxf

技术要求 Technical Requirements

= L₂ 物理摆长（关键尺寸）

6061-T6 铝合金板，t=4 mm 与 P01 同批料更好（重量一致）

② 加工方式
激光切割（首选）
③ 表面处理
两面 240# 砂纸打磨（哑光）
棱倒角 C0.5×45°，孔口去毛刺
未标注：GB/T 1804-m 中等级
A-B 孔心距 ±0.1（直接影响 L₂）
两摆臂建议同时下料、同板加工，
便于一致性控制。

侧视图 Side View（5:1）

标题块 Title Block

⌀3.4（M3 中配过孔）
穿 M3×16 不锈钢内六角螺栓
拧入 P03 钢配重盘 M3 螺纹

轴承在 P01 摆臂 1 下端

⚠️ 给加工厂的备注
· A-B 孔心距 200±0.1 是物理摆长 L₂，必须钻模一次装夹加工
· B 孔 ⌀3.4 不要做 M3 螺纹（螺纹在 P03 钢盘上），这里是 ISO 中配过孔（slip-fit）
· P01 与 P02 摆臂建议同板下料（同一块 6061 铝板），保证密度一致性

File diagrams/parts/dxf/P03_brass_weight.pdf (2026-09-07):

P03 · 配重盘（Steel Weight Disc，v2: 45# 碳钢） | 单位 mm · 俯视 5:1 / 剖视 5:1 · GB/T 1804-m

⌀30 ±0.1

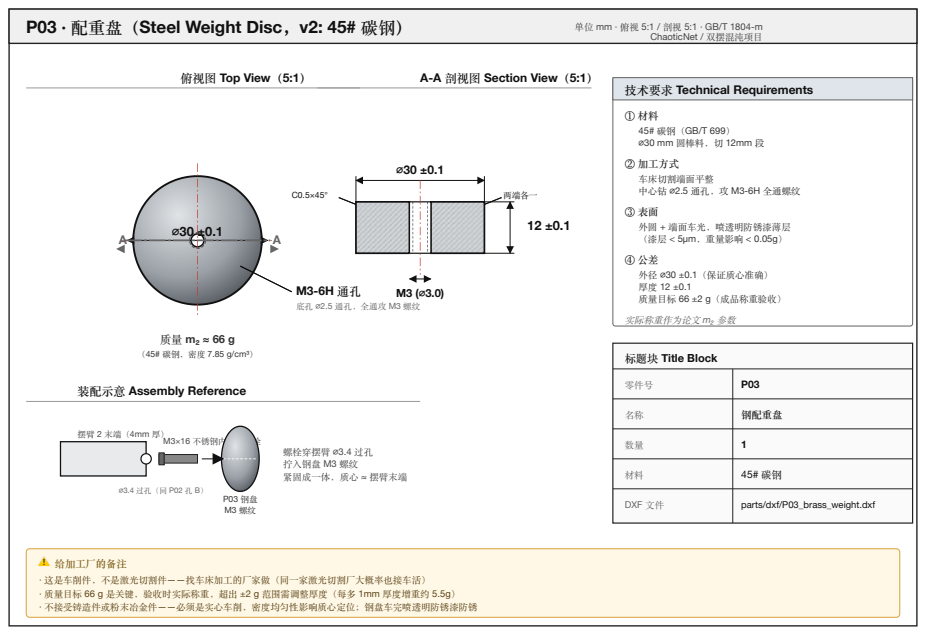
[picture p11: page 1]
ChaoticNet / 双摆混沌项目; 两端各一; M3×16 不锈钢内六角螺栓; 零件号; 钢配重盘; DXF 文件; parts/dxf/P03_brass_weight.dxf

俯视图 Top View（5:1）

A-A 剖视图 Section View（5:1）

技术要求 Technical Requirements

⌀30 mm 圆棒料，切 12mm 段
② 加工方式
车床切割端面平整
中心钻 ⌀2.5 通孔，攻 M3-6H 全通螺纹
外圆 + 端面车光，喷透明防锈漆薄层
（漆层 < 5μm，重量影响 < 0.05g）
外径 ⌀30 ±0.1（保证质心准确）
厚度 12 ±0.1 质量目标 66 ±2 g（成品称重验收）

底孔 ⌀2.5 通孔，全通攻 M3 螺纹

实际称重作为论文 m₂ 参数

（45# 碳钢，密度 7.85 g/cm³）

标题块 Title Block

装配示意 Assembly Reference

螺栓穿摆臂 ⌀3.4 过孔
拧入钢盘 M3 螺纹
紧固成一体，质心 ≈ 摆臂末端

⚠️ 给加工厂的备注
· 这是车削件，不是激光切割件——找车床加工的厂家做（同一家激光切割厂大概率也接车活）
· 质量目标 66 g 是关键，验收时实际称重，超出 ±2 g 范围需调整厚度（每多 1mm 厚度增重约 5.5g）
· 不接受铸造件或粉末冶金件——必须是实心车削，密度均匀性影响质心定位；钢盘车完喷透明防锈漆防锈

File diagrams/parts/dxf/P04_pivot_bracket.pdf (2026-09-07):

P04 · 主轴座（Pivot Bearing Bracket） | 单位 mm · 比例 4:1 · GB/T 1804-m

## 前视图 Front View（4:1）

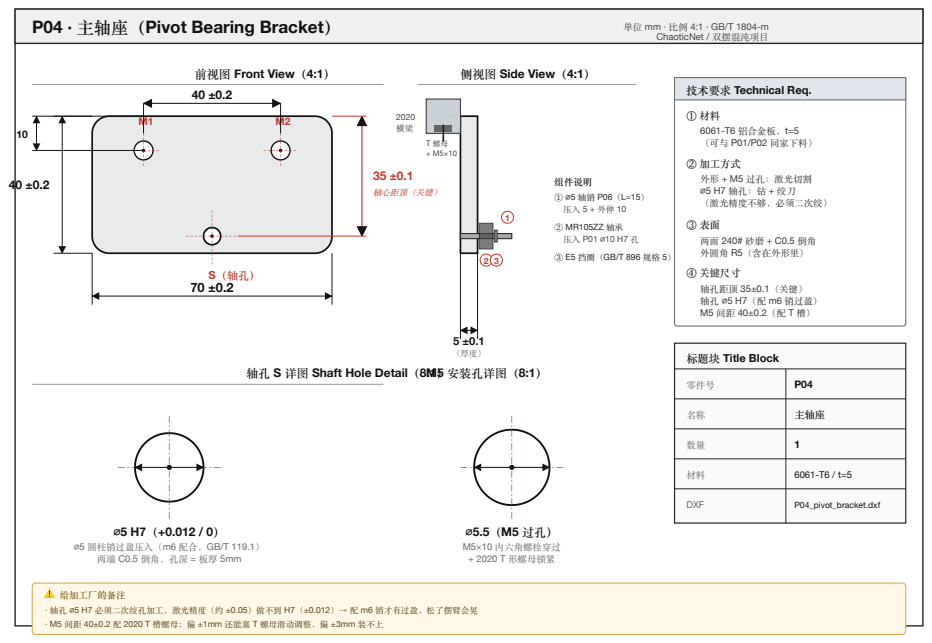
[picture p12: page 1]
ChaoticNet / 双摆混沌项目; 轴心距顶（关键）; M5 安装孔详图（8:1）; ⌀5.5（M5 过孔） M5×10 内六角螺栓穿过 + 2020 T 形螺母锁紧; 零件号; 主轴座; DXF; P04_pivot_bracket.dxf

侧视图 Side View（4:1）

技术要求 Technical Req.

6061-T6 铝合金板，t=5 （可与 P01/P02 同家下料）

② 加工方式
外形 + M5 过孔：激光切割
（激光精度不够，必须二次绞）
外圆角 R5（含在外形里）
④ 关键尺寸
轴孔距顶 35±0.1（关键）
轴孔 ⌀5 H7（配 m6 销过盈）

组件说明

标题块 Title Block

轴孔 S 详图 Shaft Hole Detail（8:1）

⌀5 圆柱销过盈压入（m6 配合，GB/T 119.1）

⚠️ 给加工厂的备注
· 轴孔 ⌀5 H7 必须二次绞孔加工，激光精度（约 ±0.05）做不到 H7（±0.012）→ 配 m6 销才有过盈，松了摆臂会晃
· M5 间距 40±0.2 配 2020 T 槽螺母；偏 ±1mm 还能塞 T 螺母滑动调整，偏 ±3mm 装不上

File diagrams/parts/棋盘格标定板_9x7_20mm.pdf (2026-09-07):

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

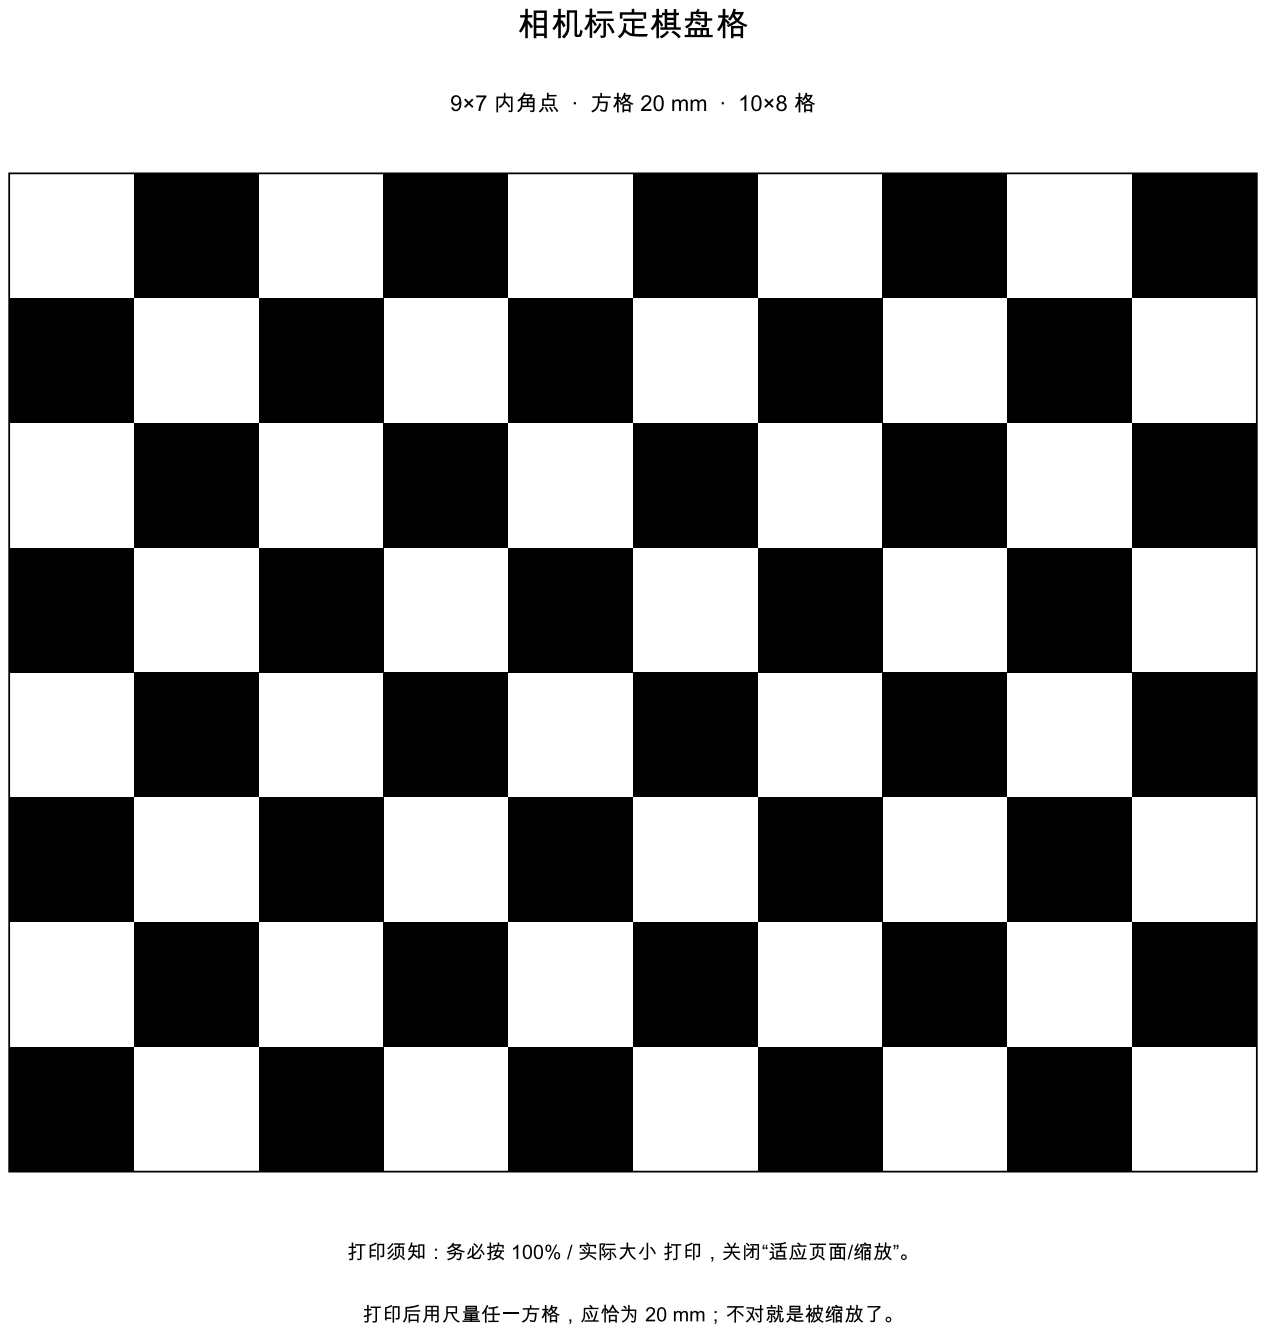
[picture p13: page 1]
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

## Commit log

2026-09-07 ChaoticNet 公开发布：双摆混沌预测的可复现最小集
    物理约束神经网络 + 储池计算在真实双摆上的 sim->real 零样本预测。
    本次发布为可复现最小集，含：
    - sim/ rc/ tracking/ tools/ 仿真、模型、视觉追踪与分析脚本
    - data/tracking_windows/ 29 段真实轨迹分析窗（每段起始 600 帧，2.95 MB，附 MD5SUMS）
    - data/pinn|hybrid/model.pt 冻结的 canonical 模型权重
    - data/sensitivity_correct/ 修正协议下的初值敏感性扫描结果
    - data/esn_grid_real/ ESN 超参网格对照（排除基线被人为削弱）
    - data/esn_closedloop_fix/ ESN 闭环起跑点修正的逐位等价验证与影响面清单
    -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
    [P01_arm_1.dxf, P02_arm_2.dxf, P03_brass_weight.dxf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]
2026-09-07 论文终稿修订：补优势边界、敏感性表排序说明、Spearman 实证与口径澄清
    在 a08dbe9 的 ESN 闭环修正基础上继续收口：
    - 补「物理先验的优势边界」：ESN 网格沿引入窗 2/4/8/16/32s 的二维扫描表明，
    约在 16s 引入窗处纯数据基线反超零样本物理模型。据此把结论限定在其成立条件上——
    物理先验的价值出现在真实数据稀缺的一侧。此前该结果只在 data/esn_grid_real/summary.md。
    - 说明敏感性表无扰动行与主表的顺序反转成因（单次冻结权重 vs 多次重训，两者分布高度重叠）
    - 视界随释放角下降由裸断言改为 Spearman 秩相关实证，并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
2026-09-08 论文修订：修正弱混沌档删失表述与统计口径声明，补编译故障排查
    - 弱混沌档（38°–60°）原写「该档 ESN 全部右删失」，实为 3 段中 2 段；
    补每档段数与「仅作定性提示」的限定。
    - 80° 以上档倍数 3.08/3.29 → 3.09/3.30（原值由舍入后中位反算）。
    - Wilcoxon 脚注原称与表体同口径，实为聚合次序不同，改为写明两种次序及其一致结论。
    - 阈值稳健性核验使用另行播种重训的一批运行，与主表非同一批，已声明其倍数差异。
    - 编译说明补两个实测踩到的失败模式：漏设 TEXINPUTS 会使 xelatex 陷入
    \supercite/\cite 无限递归并把日志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

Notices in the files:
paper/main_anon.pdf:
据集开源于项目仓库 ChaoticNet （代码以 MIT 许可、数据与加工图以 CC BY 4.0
